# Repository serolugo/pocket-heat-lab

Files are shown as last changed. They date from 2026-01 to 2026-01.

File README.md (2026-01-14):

# Pocket Heat Lab

## 📌 Overview
**Pocket Heat Lab** is a compact thermal control laboratory designed to demonstrate and experiment with **digital PID control** on a real physical system.

The project uses an **ESP32** to regulate the temperature of a **BJT transistor used as a thermal plant**, leveraging PWM control, real-time sensing with a thermistor, and external visualization tools for tuning and analysis.

This project was developed with an educational focus, bridging **control theory**, **embedded systems**, and **practical electronics**.

---

## 🔥 System Concept
A BJT transistor, when biased appropriately, dissipates power and generates heat.  
This behavior is exploited as a **slow, inertial thermal plant**, ideal for demonstrating PID control principles.

The ESP32:
- Reads temperature from a 10 kΩ NTC thermistor
- Computes a digital PID controller
- Drives the transistor using a **limited PWM signal**
- Streams data over serial for monitoring and tuning

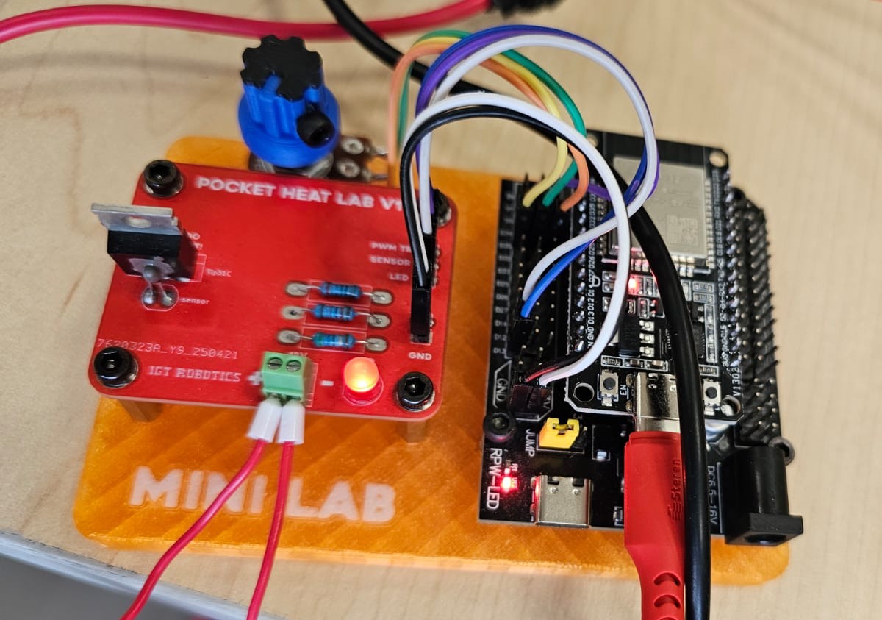
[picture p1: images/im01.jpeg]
System overview


---

## 🎯 Objectives
- Implement a **digital PID controller** on an ESP32
- Regulate the temperature of a real thermal system
- Explore tuning effects on stability and response
- Provide real-time visualization and interaction
- Maintain safe operating limits for the power device

---

## 🧩 Hardware Overview
- **Microcontroller:** ESP32
- **Thermal plant:** BJT transistor (power dissipation)
- **Temperature sensor:** 10 kΩ NTC thermistor
- **Thermal coupling:** Thermistor mounted with thermal paste
- **PCB:** Custom-designed board

Thermal contact between the sensor and the transistor is critical for accurate control:

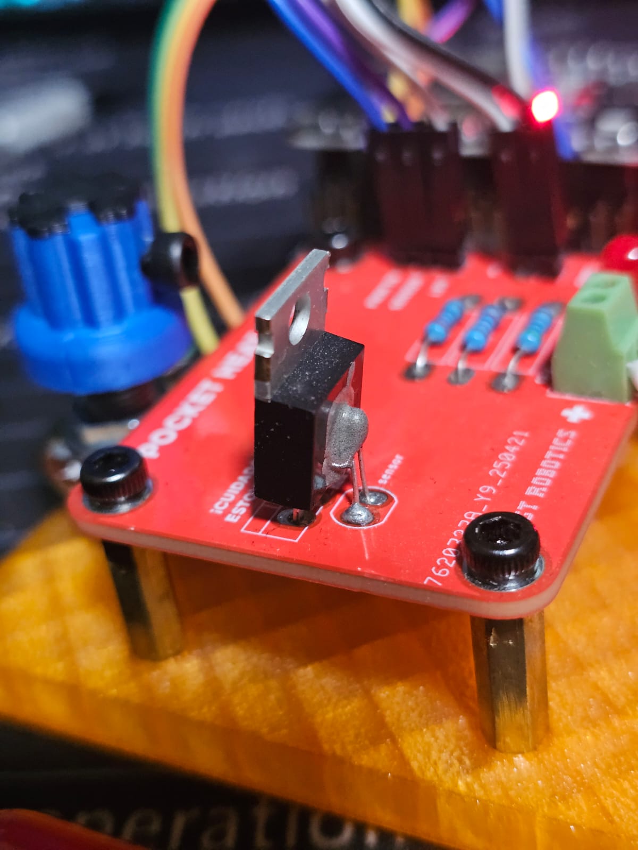
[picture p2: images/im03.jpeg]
Thermistor coupling


---

## ⚡ Safety & Design Constraints
To prevent damage and unsafe operation:
- PWM output to the transistor is **limited to 28 / 255**
- Maximum power dissipation kept below ~2 W
- Sampling and control period set to **100 ms**
- Anti-windup implemented in the integral term

These constraints ensure stable behavior even under poor tuning conditions.

---

## 🧠 Control Algorithm
- **Controller type:** Digital PID
- **Sampling period:** 100 ms
- **Setpoint selection:** Potentiometer (25 °C – 80 °C)
- **Anti-windup:** Integral clamping
- **Output saturation:** PWM constrained

Final stable gains obtained experimentally:
- `Kp = 4`
- `Ki = 0.15`
- `Kd = 2.1`

---

## 📈 Visualization & Tuning
To facilitate tuning and understanding of system behavior, a **Python-based GUI** was implemented using:
- `Tkinter`
- `Matplotlib`
- `PySerial`

Features:
- Real-time plotting of temperature and setpoint
- Live adjustment of PID gains via sliders
- Serial data logging to CSV for offline analysis

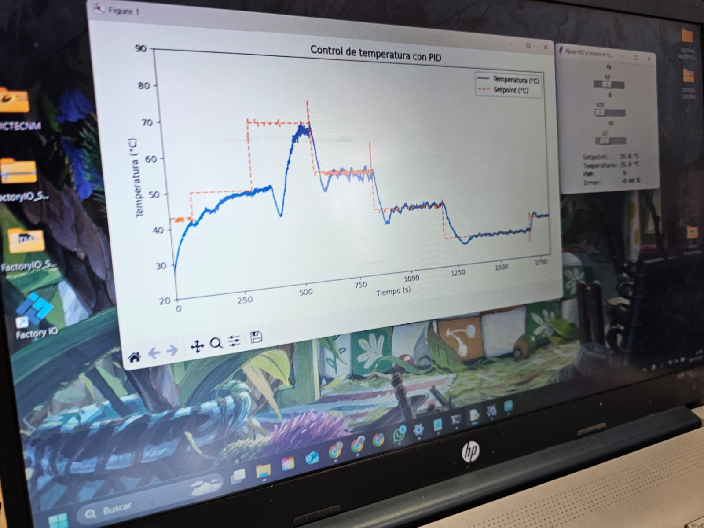
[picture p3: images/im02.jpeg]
Live monitoring


---

## 📊 Results
The system demonstrates:
- Stable temperature regulation
- Clear response to setpoint changes
- Expected thermal inertia behavior
- Sensitivity to PID tuning (trial-and-error process)

Example plots of recorded data:

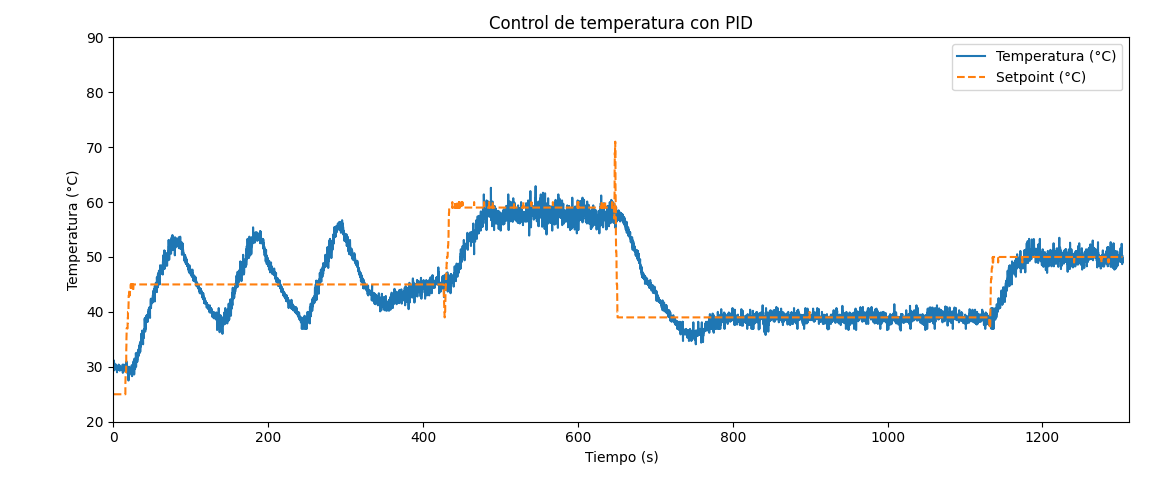
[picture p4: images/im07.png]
Control response
  
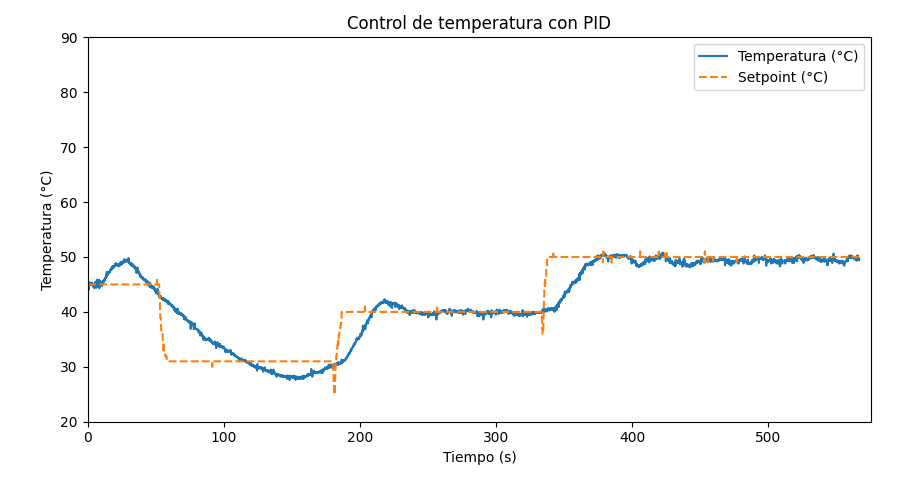
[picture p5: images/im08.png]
Setpoint tracking


---

## 🖥 PCB Design
The project includes a custom PCB designed specifically for this laboratory setup.

- Rendered PCB view:
  
<p align="center">
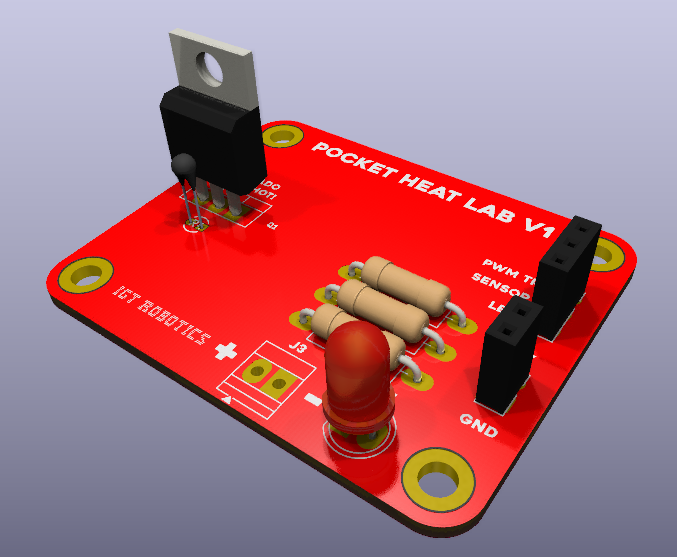
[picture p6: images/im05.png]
PCB render
  
</p>

- PCB layout:
  
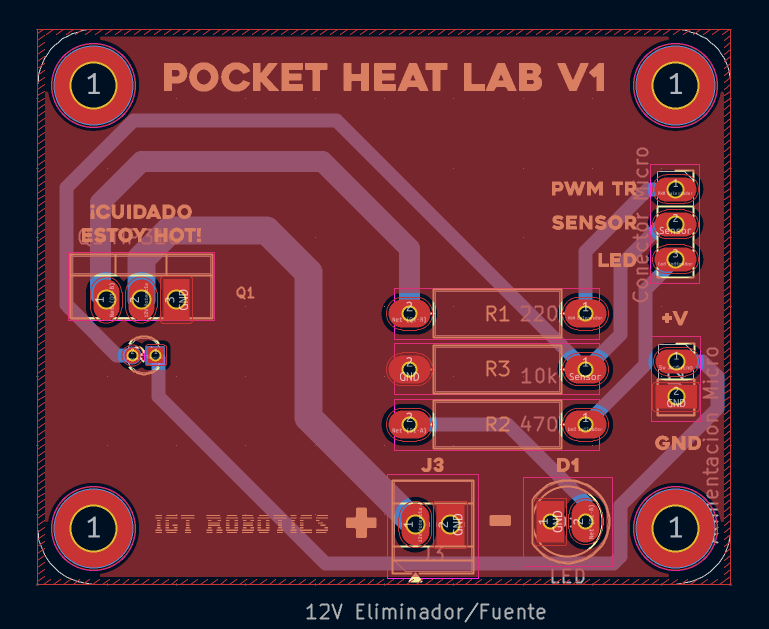
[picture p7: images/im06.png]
PCB layout
  

---

## 🎥 Demo
The following GIF shows the system operating in real time, including temperature response and control action:

<p align="center">
  System demo
</p>

---

## 📁 Repository Structure
    pocket-heat-lab/
    ├── firmware/ # ESP32 PID controller code
    ├── software/ # Python visualization and tuning tools
    ├── hardware/ # PCB files
    ├── images/ # Documentation images and GIFs
    ├── docs/
    │ └── CONTROL_TEMPERATURA.pdf
    └── README.md

---

## 🚀 Project Status
✅ Implemented and tested  
✅ Real-time visualization working  
🔧 Open to future improvements (filtering, better sensing, power stage refinement)

---

## 🔮 Possible Improvements
- Signal filtering for temperature measurements
- Dedicated power stage (MOSFET instead of BJT)
- Higher-resolution PWM
- Model-based tuning methods
- Closed-loop current monitoring

---
## 📜 License
MIT License

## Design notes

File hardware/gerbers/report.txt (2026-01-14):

Plotted to 'C:\DOCUMENTOS\14.- Proyectos\Electronica\pocket-heat-lab\hardware\gerbers\pocket-heat-lab-F_Cu.gbr'.
Plotted to 'C:\DOCUMENTOS\14.- Proyectos\Electronica\pocket-heat-lab\hardware\gerbers\pocket-heat-lab-B_Cu.gbr'.
Plotted to 'C:\DOCUMENTOS\14.- Proyectos\Electronica\pocket-heat-lab\hardware\gerbers\pocket-heat-lab-F_Paste.gbr'.
Plotted to 'C:\DOCUMENTOS\14.- Proyectos\Electronica\pocket-heat-lab\hardware\gerbers\pocket-heat-lab-B_Paste.gbr'.
Plotted to 'C:\DOCUMENTOS\14.- Proyectos\Electronica\pocket-heat-lab\hardware\gerbers\pocket-heat-lab-F_Silkscreen.gbr'.
Plotted to 'C:\DOCUMENTOS\14.- Proyectos\Electronica\pocket-heat-lab\hardware\gerbers\pocket-heat-lab-B_Silkscreen.gbr'.
Plotted to 'C:\DOCUMENTOS\14.- Proyectos\Electronica\pocket-heat-lab\hardware\gerbers\pocket-heat-lab-F_Mask.gbr'.
Plotted to 'C:\DOCUMENTOS\14.- Proyectos\Electronica\pocket-heat-lab\hardware\gerbers\pocket-heat-lab-B_Mask.gbr'.
Plotted to 'C:\DOCUMENTOS\14.- Proyectos\Electronica\pocket-heat-lab\hardware\gerbers\pocket-heat-lab-Edge_Cuts.gbr'.
Created Gerber job file 'C:\DOCUMENTOS\14.- Proyectos\Electronica\pocket-heat-lab\hardware\gerbers\pocket-heat-lab-job.gbrjob'.
Info: Done.
Info: Done.

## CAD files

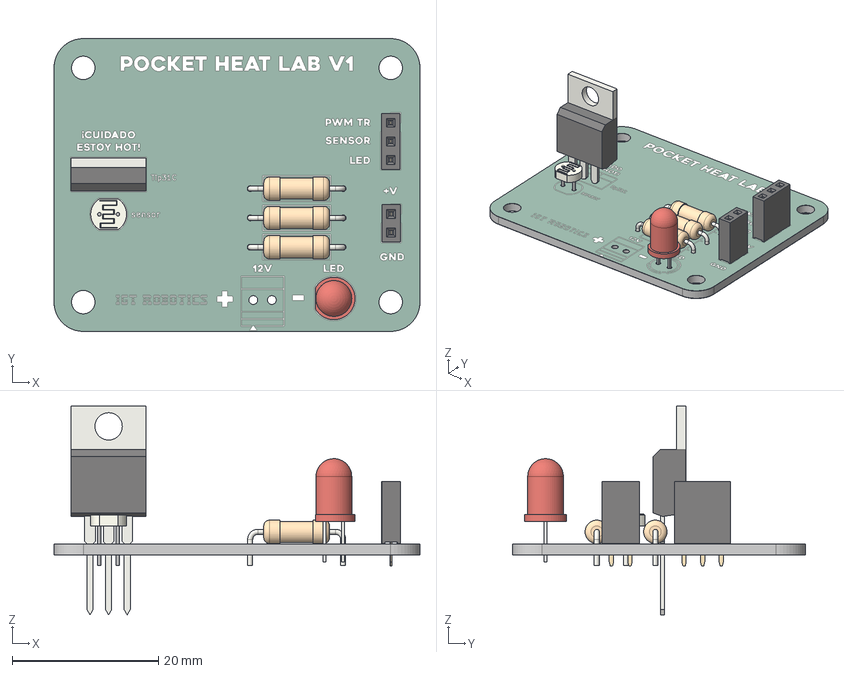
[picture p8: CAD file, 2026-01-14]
hardware/pcb/pocket-heat-lab/pocket-heat-lab.step
50.0 x 40.0 x 28.5 mm
R_Axial_DIN0309_L9.0mm_D3.2mm_P12.70mm_Horizontal x 3
PinSocket_1x03_P2.54mm_Vertical
LED_D5.0mm
PinSocket_1x02_P2.54mm_Vertical
TO-220-3_Vertical
R_LDR_4.9x4.2mm_P2.54mm_Vertical
MINI HEAT LAB_silkscreen
MINI HEAT LAB_soldermask
MINI HEAT LAB_PCB

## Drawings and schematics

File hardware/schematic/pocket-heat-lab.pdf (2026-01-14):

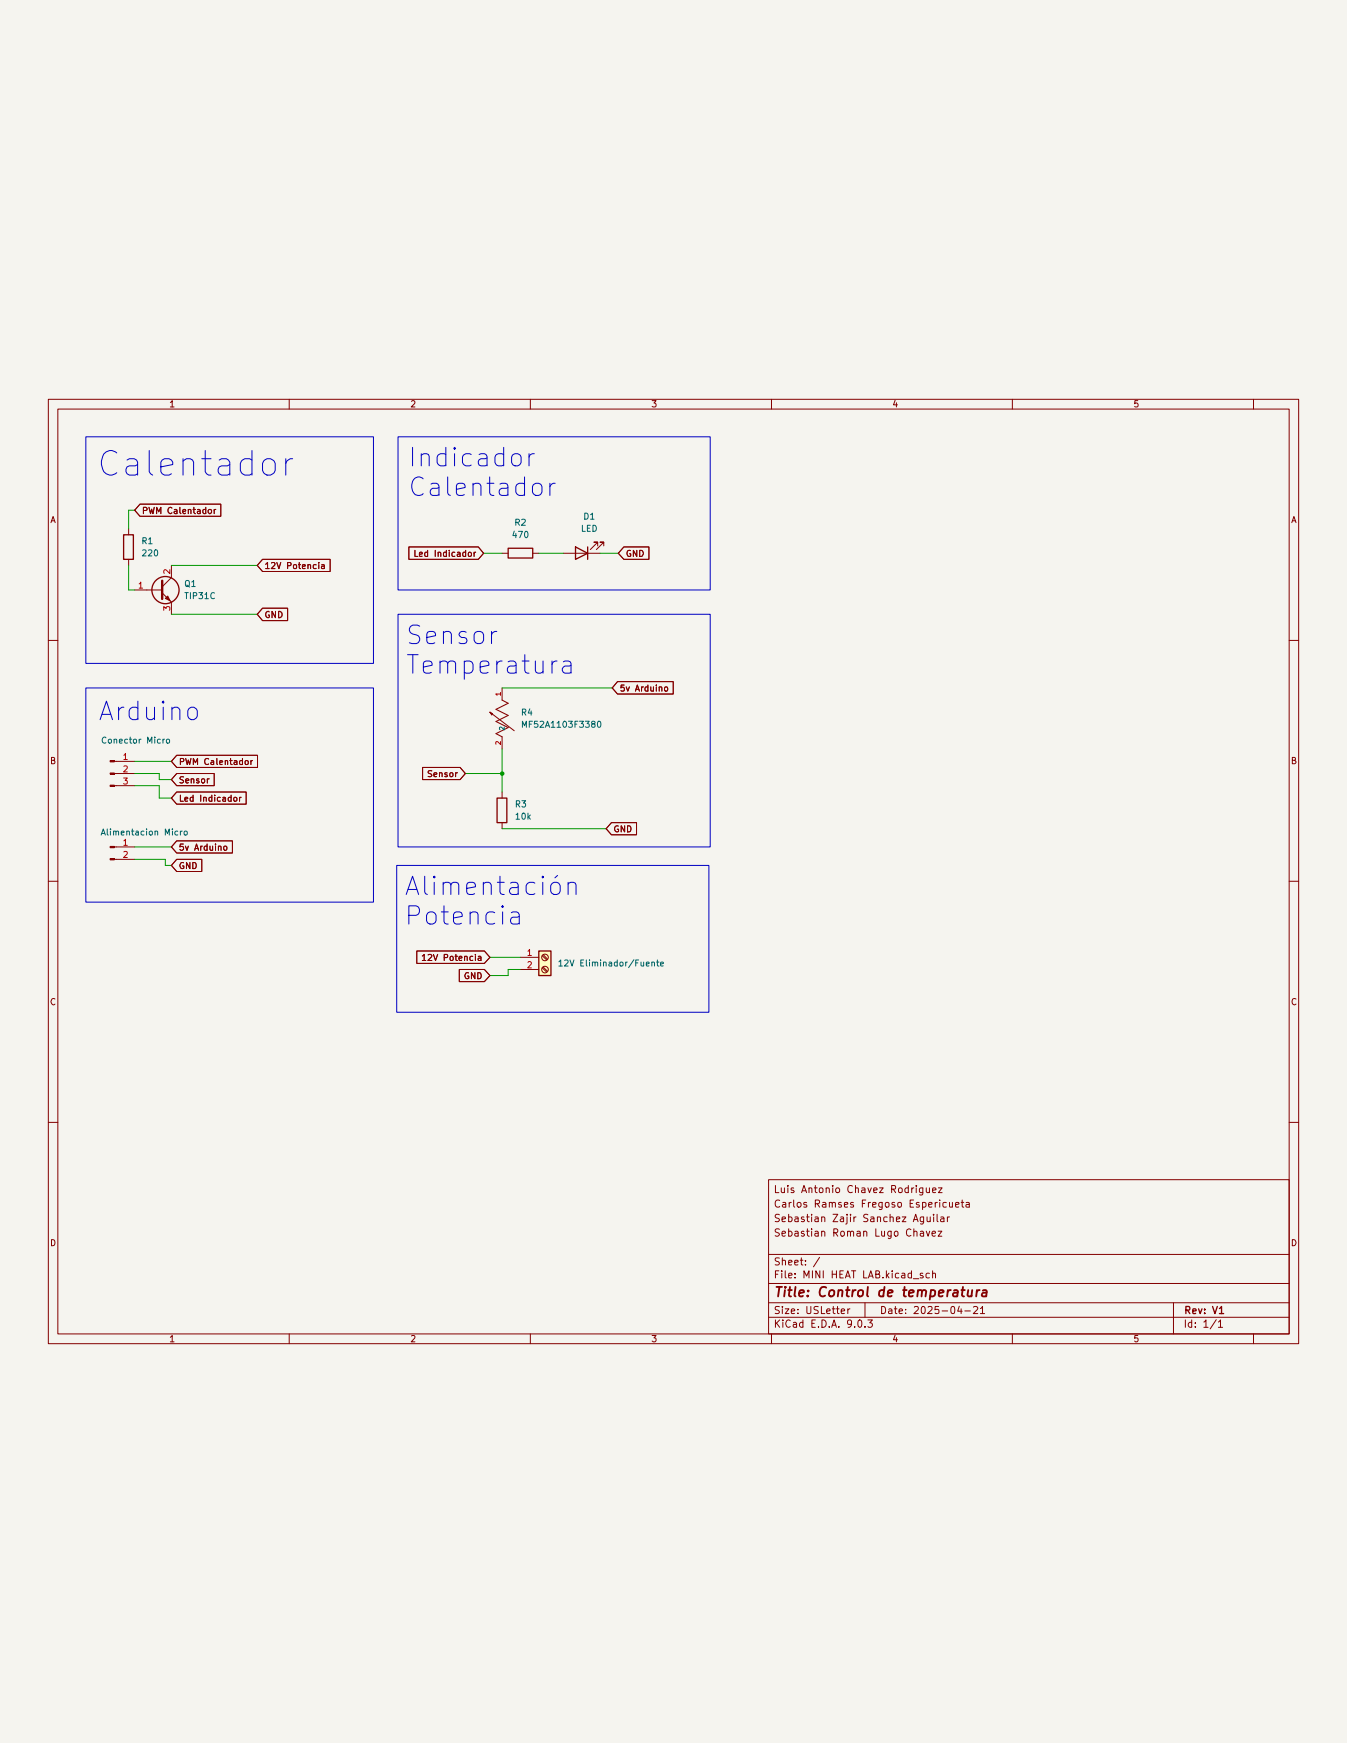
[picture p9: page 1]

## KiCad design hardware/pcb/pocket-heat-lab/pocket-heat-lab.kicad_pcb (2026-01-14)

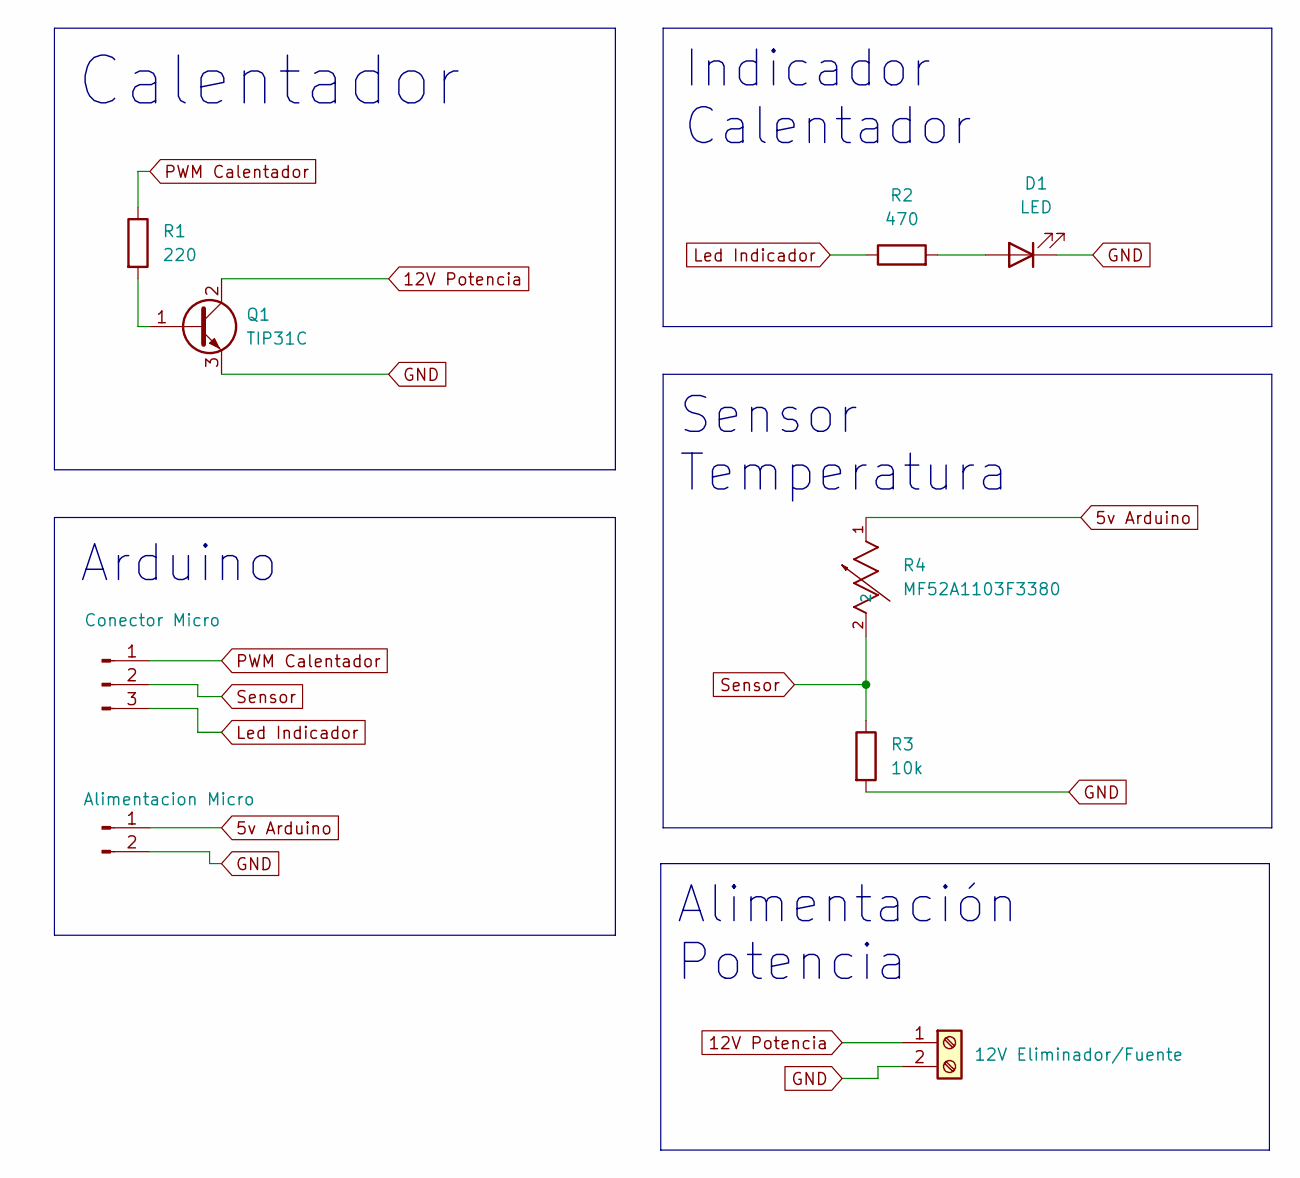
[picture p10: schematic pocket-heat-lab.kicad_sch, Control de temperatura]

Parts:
D1: LED; LED_D5.0mm
J1: Conector Micro; PinSocket_1x03_P2.54mm_Vertical
J2: Alimentacion Micro; PinSocket_1x02_P2.54mm_Vertical
J3: 12V Eliminador/Fuente; TerminalBlock_Xinya_XY308-2.54-2P_1x02_P2.54mm_Horizontal
Q1: TIP31C; TO-220-3_Vertical
R1: 220; R_Axial_DIN0309_L9.0mm_D3.2mm_P12.70mm_Horizontal
R2: 470; R_Axial_DIN0309_L9.0mm_D3.2mm_P12.70mm_Horizontal
R3: 10k; R_Axial_DIN0309_L9.0mm_D3.2mm_P12.70mm_Horizontal
R4: MF52A1103F3380; TRES_MF52-A_CTM; MANUFACTURER_PART_NUMBER MF52A1103F3380

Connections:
5v Arduino: J2.1, R4.1
12V Potencia: J3.1, Q1.2 (C)
GND: D1.1 (K), J2.2, J3.2, Q1.3 (E), R3.2
Led Indicador: J1.3, R2.1
unnamed: D1.2 (A), R2.2
unnamed: Q1.1 (B), R1.2
PWM Calentador: J1.1, R1.1
Sensor: J1.2, R3.1, R4.2

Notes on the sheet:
Sensor Temperatura
Alimentación Potencia
Indicador Calentador
Calentador
Arduino

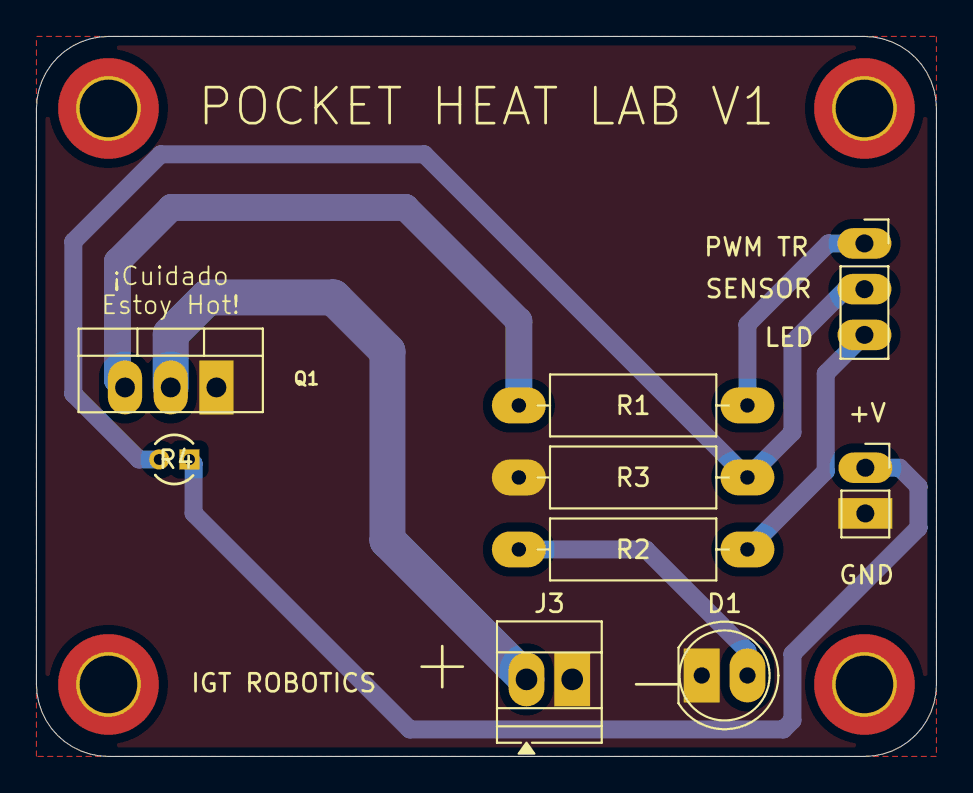
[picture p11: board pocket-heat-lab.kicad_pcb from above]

Board: 2 copper layers, 50.0 x 40.0 mm, 9 parts (0 on the bottom side), 8 nets.

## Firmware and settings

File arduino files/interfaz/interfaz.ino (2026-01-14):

#include <Arduino.h>

// Pines
const int sensorPin = 34;   // Entrada del termistor
const int pwmHeater = 13;   // Salida PWM al transistor
const int pwmLed = 12;      // Salida PWM al LED
const int potPin = 35;      // Potenciómetro para setpoint

// Parámetros del termistor
const float referenciaV = 3.3;
const float resistenciaTermistor = 10000.0; // 10k Ohm
const int adcMaxValue = 4095;
const float BETA = 3950.0;
const float T0_K = 25.0 + 273.15; // Kelvin

// PID
float Kp = 2.5;
float Ki = 0.4;
float Kd = 3.5;

float error = 0.0;
float lastError = 0.0;
float integral = 0.0;
float derivative = 0.0;
float salidaPID = 0.0;

// Tiempo PID
unsigned long lastTime = 0;
float deltaTime = 0.1;  // Valor inicial seguro

// Muestreo
unsigned long lastSampleTime = 0;
const unsigned long sampleInterval = 100; // cada 100 ms

// Temperatura
float temperaturaC = 0.0;
float resistenciaMedida = 0.0;
float voltajeTermistor = 0.0;

// ----------------------------
// Función para lectura serial PID
void checkSerialCommands() {
  if (Serial.available()) {
    String input = Serial.readStringUntil('\n');
    input.trim();
    if (input.startsWith("K ")) {
      float newKp, newKi, newKd;
      int matched = sscanf(input.c_str(), "K %f %f %f", &newKp, &newKi, &newKd);
      if (matched == 3) {
        Kp = newKp;
        Ki = newKi;
        Kd = newKd;
        Serial.printf("PID actualizado: Kp=%.2f Ki=%.2f Kd=%.2f\n", Kp, Ki, Kd);
      }
    }
  }
}
// ----------------------------

void setup() {
  Serial.begin(115200);
  pinMode(sensorPin, INPUT);
  pinMode(pwmHeater, OUTPUT);
  pinMode(pwmLed, OUTPUT);
  pinMode(potPin, INPUT);
  lastTime = millis();
}

void loop() {
  unsigned long now = millis();

  // Leer comandos del puerto serial
  checkSerialCommands();

  // Ejecutar solo cada 100 ms
  if (now - lastSampleTime >= sampleInterval) {
    lastSampleTime = now;

    // Leer temperatura
    int valorADC = analogRead(sensorPin);
    voltajeTermistor = (valorADC / float(adcMaxValue)) * referenciaV;
    resistenciaMedida = (resistenciaTermistor * (referenciaV - voltajeTermistor)) / voltajeTermistor;
    float tempK = 1.0 / ((log(resistenciaMedida / resistenciaTermistor) / BETA) + (1.0 / T0_K));
    temperaturaC = tempK - 273.15;

    // Leer setpoint desde potenciómetro
    int potValue = analogRead(potPin);
    float tempSetpoint = map(potValue, 0, 4095, 25, 80);

    // Calcular deltaTime
    deltaTime = (now - lastTime) / 1000.0;
    if (deltaTime <= 0) deltaTime = 0.01;
    lastTime = now;

    // PID
    error = tempSetpoint - temperaturaC;
    integral += error * deltaTime;

    // Anti-windup
    if (integral > 100) integral = 100;
    if (integral < -100) integral = -100;

    derivative = (error - lastError) / deltaTime;
    salidaPID = Kp * error + Ki * integral + Kd * derivative;
    lastError = error;

    // PWM limitado (0 a 28)
    int pwmOut = constrain((int)salidaPID, 0, 28);
    analogWrite(pwmHeater, pwmOut);
    analogWrite(pwmLed, pwmOut);

    // Error en porcentaje
    float porcentajeError = (error / tempSetpoint) * 100.0;

    // Serial tabulado para Python
    Serial.printf("Setpoint: %5.1f\tTemp: %5.1f\tPWM: %2d\tError: %6.2f\n",
                  tempSetpoint, temperaturaC, pwmOut, porcentajeError);
  }
}

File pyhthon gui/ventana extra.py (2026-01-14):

import serial
import pandas as pd
import matplotlib.pyplot as plt
from matplotlib.animation import FuncAnimation
from tkinter import Tk, Scale, HORIZONTAL, Label, StringVar
import threading
import time

# Parámetros de conexión
puerto_serial = 'COM4'  # Cambia esto según tu puerto
baud_rate = 115200
archivo_csv = 'datos_pid.csv'

# Conexión serial
ser = serial.Serial(puerto_serial, baud_rate, timeout=1)
time.sleep(2)

# Variables globales
datos = {'Tiempo': [], 'Setpoint': [], 'Temperatura': [], 'PWM': [], 'Error': []}
start_time = time.time()
Kp = 2.5
Ki = 0.4
Kd = 3.5

# Variables de datos actuales
valores_actuales = {
    "setpoint": 0.0,
    "temperatura": 0.0,
    "pwm": 0,
    "error": 0.0
}

# Función para enviar PID a la ESP32
def enviar_pid():
    comando = f"K {Kp:.2f} {Ki:.2f} {Kd:.2f}\n"
    ser.write(comando.encode())

# Crear ventana con sliders y display en tiempo real
def crear_interface():
    global Kp, Ki, Kd

    def actualizar(val=None):
        nonlocal slider_kp, slider_ki, slider_kd
        global Kp, Ki, Kd
        Kp = slider_kp.get()
        Ki = slider_ki.get()
        Kd = slider_kd.get()
        enviar_pid()

    root = Tk()
    root.title("Ajuste PID y Lectura en Tiempo Real")

    # Sliders
    Label(root, text="Kp").pack()
    slider_kp = Scale(root, from_=0, to=10, resolution=0.1, orient=HORIZONTAL, command=actualizar)
    slider_kp.set(Kp)
    slider_kp.pack()

    Label(root, text="Ki").pack()
    slider_ki = Scale(root, from_=0, to=5, resolution=0.05, orient=HORIZONTAL, command=actualizar)
    slider_ki.set(Ki)
    slider_ki.pack()

    Label(root, text="Kd").pack()
    slider_kd = Scale(root, from_=0, to=10, resolution=0.1, orient=HORIZONTAL, command=actualizar)
    slider_kd.set(Kd)
    slider_kd.pack()

    # Etiquetas de datos actuales
    estado_var = StringVar()
    estado_label = Label(root, textvariable=estado_var, font=('Consolas', 12), justify='left')
    estado_label.pack(pady=10)

    def actualizar_valores():
        while True:
            texto = (
                f"Setpoint:    {valores_actuales['setpoint']:.1f} °C\n"
                f"Temperatura: {valores_actuales['temperatura']:.1f} °C\n"
                f"PWM:         {valores_actuales['pwm']:2d}\n"
                f"Error:       {valores_actuales['error']:.2f} %"
            )
            estado_var.set(texto)
            time.sleep(0.2)

    threading.Thread(target=actualizar_valores, daemon=True).start()
    root.mainloop()

# Iniciar GUI en hilo aparte
threading.Thread(target=crear_interface, daemon=True).start()

# Gráfica
fig, ax = plt.subplots()
line_temp, = ax.plot([], [], label='Temperatura (°C)')
line_set, = ax.plot([], [], label='Setpoint (°C)', linestyle='--')
ax.set_ylim(20, 90)
ax.set_xlim(0, 60)
ax.set_xlabel('Tiempo (s)')
ax.set_ylabel('Temperatura (°C)')
ax.legend()
plt.title('Control de temperatura con PID')

def animar(i):
    global datos
    while ser.in_waiting:
        linea = ser.readline().decode().strip()
        if linea.startswith("Setpoint:"):
            try:
                partes = linea.replace("Setpoint:", "").replace("Temp:", "").replace("PWM:", "").replace("Error:", "").replace("°C", "").replace("%", "").split()
                if len(partes) >= 4:
                    tiempo_actual = time.time() - start_time
                    setpoint = float(partes[0])
                    temperatura = float(partes[1])
                    pwm = int(partes[2])
                    error = float(partes[3])

                    # Guardar valores actuales
                    valores_actuales['setpoint'] = setpoint
                    valores_actuales['temperatura'] = temperatura
                    valores_actuales['pwm'] = pwm
                    valores_actuales['error'] = error

                    # Guardar datos
                    datos['Tiempo'].append(tiempo_actual)
                    datos['Setpoint'].append(setpoint)
                    datos['Temperatura'].append(temperatura)
                    datos['PWM'].append(pwm)
                    datos['Error'].append(error)

                    pd.DataFrame(datos).to_csv(archivo_csv, index=False)

                    if tiempo_actual > ax.get_xlim()[1]:
                        ax.set_xlim(0, tiempo_actual + 10)

                    line_temp.set_data(datos['Tiempo'], datos['Temperatura'])
                    line_set.set_data(datos['Tiempo'], datos['Setpoint'])

            except Exception as e:
                print("Error:", e)

    return line_temp, line_set

ani = FuncAnimation(fig, animar, interval=200)
plt.tight_layout()
plt.show()

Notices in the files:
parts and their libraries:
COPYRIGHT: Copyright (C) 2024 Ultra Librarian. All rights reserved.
